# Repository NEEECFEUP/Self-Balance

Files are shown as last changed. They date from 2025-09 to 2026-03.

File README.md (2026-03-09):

# Self Balance

O projeto implementa um controlador PID com base na distância a uma bola e ajusta a posição do servo para manter a distância próxima do **setpoint** definido.

Um **joystick** permite alterar o setpoint e ajustar parâmetros do controlador (Ki e Kd) em tempo real. Um **LCD 16x2 RGB** mostra informação do sistema.

---

## Funcionalidades

- Controlo **PID em tempo real**
- Sensor de distância **VL53L0X**
- Ajuste de **setpoint com joystick**
- Ajuste em tempo real de **Ki e Kd**
- **Filtro passa-baixo** na leitura do sensor
- **Filtro na derivada** para reduzir ruído
- Visualização em **LCD 16x2**
- Debug via **Arduino Serial Plotter**
- Frequência de controlo: **100 Hz**

---

## Hardware

- Arduino
- Sensor **VL53L0X**
- Servo da Hiwonder
- LCD **RGB 16x2 (I2C)**
- Joystick analógico
- Botões de reset

---

## Bibliotecas

Instalar no Arduino IDE:

- `SoftwareSerial`
- `Wire`
- `DFRobot_VL53L0X`
- `ServoHiwonder`
- `rgb_lcd`

---

## Ligações

| Componente | Pino |
|---|---|
| Servo Controller RX | 2 |
| Servo Controller TX | 3 |
| Joystick (setpoint) | A1 |
| Botão joystick | 5 |
| Ajuste Ki | A0 |
| Reset Ki | 4 |
| Ajuste Kd | A2 |
| Reset Kd | 6 |
| VL53L0X | I2C |
| LCD RGB | I2C |

---

## Parâmetros PID

```cpp
float kp = 0.55;
float ki = 0.32;
float kd = 0.4;

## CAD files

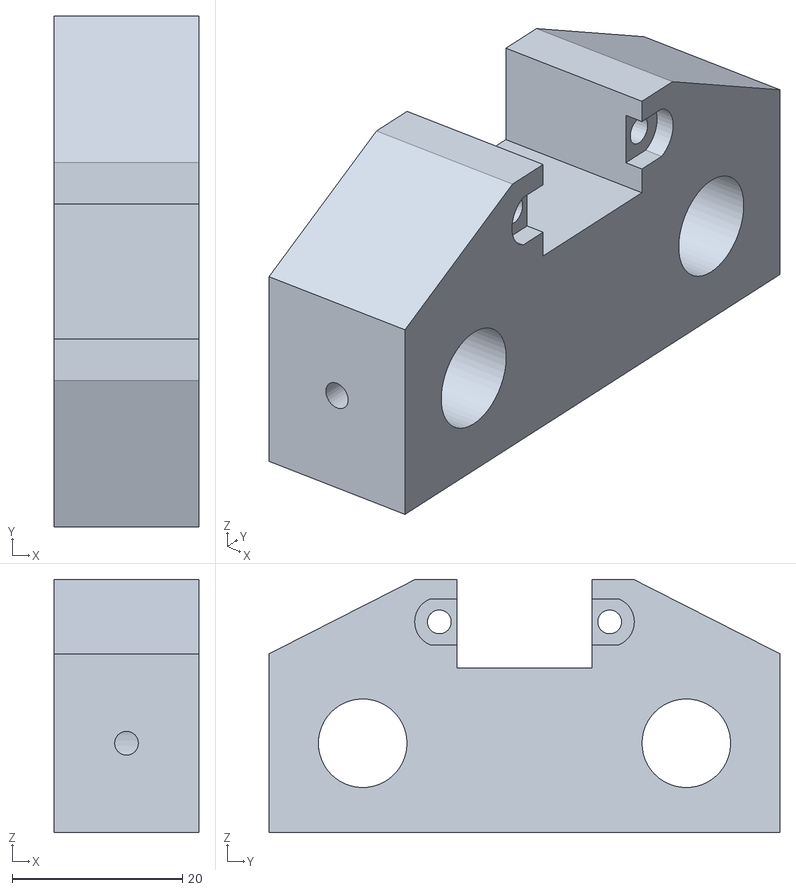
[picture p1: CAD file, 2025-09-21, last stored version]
Self-Balancing c Esteroides/End Cap w ToF.stl
17.0 x 60.0 x 29.7

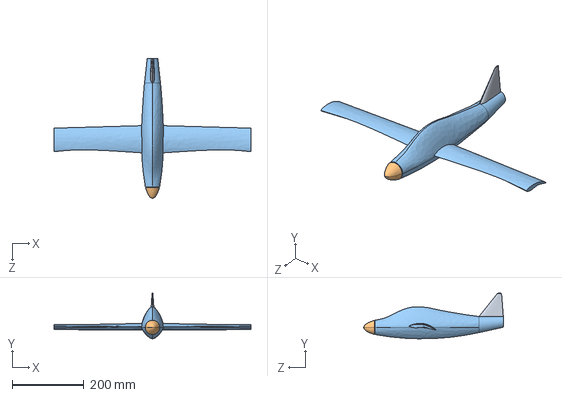
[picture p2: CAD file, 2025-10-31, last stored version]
Self_Balancing 3.0/rc-model-plane-3.snapshot.8/deneme tam çizim 1.STEP
550.0 x 127.3 x 390.0 mm

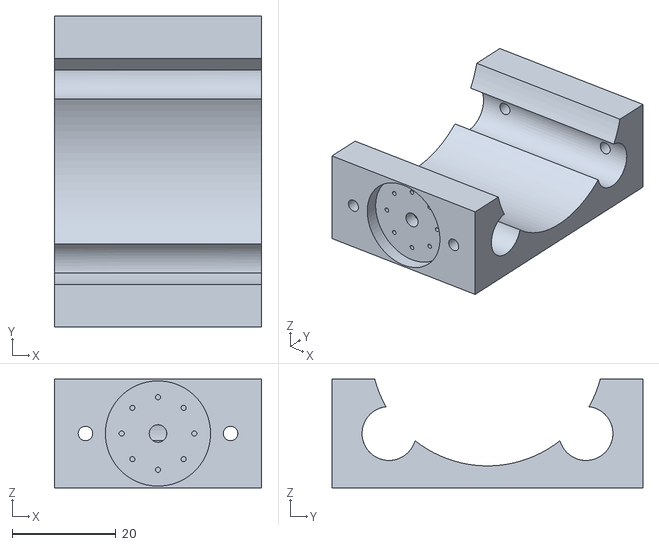
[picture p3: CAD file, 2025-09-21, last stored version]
Self-Balancing c Esteroides/Motor Stand.stl
40.0 x 60.0 x 21.0

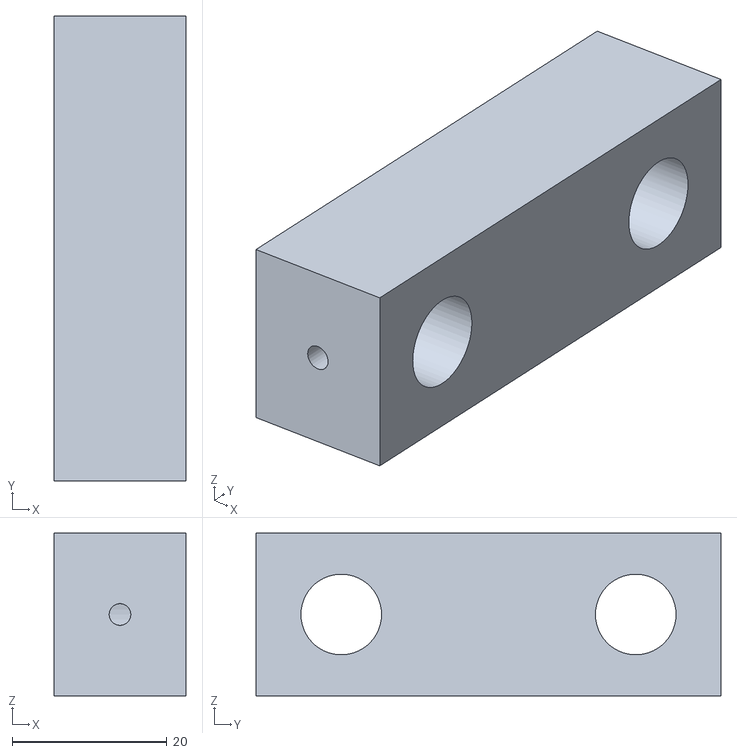
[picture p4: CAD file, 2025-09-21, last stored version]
Self-Balancing c Esteroides/End Cap.stl
17.0 x 60.0 x 21.0

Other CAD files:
Self-Balancing c Esteroides/End Cap w ToF.obj
Self-Balancing c Esteroides/End Cap.obj
Self-Balancing c Esteroides/Motor Stand.obj
Self-Balancing c Esteroides/Self-Balancing c Esteroides v1.f3d
Self_Balancing 3.0/Self-Balancing c Esteroides v10.f3d
Self_Balancing 3.0/Torre_Self_Balancing v1.f3d

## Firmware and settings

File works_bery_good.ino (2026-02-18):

#include <Arduino.h>
#include <SoftwareSerial.h>
#include <Wire.h>
#include "DFRobot_VL53L0X.h"
#include <ServoHiwonder.hpp>
#include "rgb_lcd.h"

// Declarations
SoftwareSerial serial_motors(2, 3);  // RX, TX
ServoController servoCont(serial_motors);
DFRobot_VL53L0X sensor;
rgb_lcd lcd;

// PID vars
float setpoint = 240;   // target distance (mm)

float kp = 0.55;
float ki = 0.32;
float kd = 0.4;

const int servo_center = 600;

float error = 0;
float last_error = 0;
float last_dist = setpoint;
float integral = 0;

// Update Rate
int CRF = 100;   // control rate frequecy (Hz)
const unsigned long interval_ms = 1000 / CRF;
unsigned long lastMillis = 0;
unsigned long lastLcdUpdate = 0;
const unsigned long lcdInterval = 200;   // 5 Hz

const int min_change = 2; // Muda o salto minimo em angulo para fazer, tentei diminuir o jitter mas n fez muito, baixei para 2
static int last_pos = servo_center;

const int pinAnal = A1;  // Pino analógico para o joystick
const int pinButt = 5;  // Pino butao joystick
const int pinKi = A0;  // Pino ki
const int pinRSTKi = 4;  // reset ki
const int pinKd = A2;  // mesmo para a derivada
const int pinRSTKd = 6;  

void setup() {
  Serial.begin(115200);
  serial_motors.begin(115200);

  Wire.begin();
  sensor.begin(0x50);
  sensor.setMode(sensor.eContinuous, sensor.eHigh);
  sensor.start();

  lcd.begin(16, 2);
  lcd.setCursor(0,0);
  lcd.print("Ola...");
  delay(200);

  pinMode(pinButt, INPUT_PULLUP);
  pinMode(pinRSTKi, INPUT_PULLUP);
  pinMode(pinRSTKd, INPUT_PULLUP);

  lastMillis = millis();
}

void loop() {
  unsigned long now = millis();
  if (now - lastMillis >= interval_ms) {

    unsigned long elapsed = now - lastMillis;
    float dt = elapsed / 1000.0;
    lastMillis = now;

    //joy no stick
    int joyValue = analogRead(pinAnal);
    if (joyValue > 550) {
      setpoint += 0.1;  
    }
    else if (joyValue < 470) {
      setpoint -= 0.1;  
    }
    setpoint = constrain(setpoint, 80, 300);
    if (digitalRead(pinButt) == LOW) {
      setpoint = 240;
    }

    // controlar Ki
    joyValue = analogRead(pinKi);
    if (joyValue > 550) {
      ki += 0.001;  
    }
    else if (joyValue < 470) {
      ki -= 0.001;  
    }
    if (digitalRead(pinRSTKi) == LOW) {
      ki = 0.32;
    }

    // controlar kd
    joyValue = analogRead(pinKd);
    if (joyValue > 550) {
      kd += 0.001;  
    }
    else if (joyValue < 470) {
      kd -= 0.001;  
    }
    if (digitalRead(pinRSTKd) == LOW) {
      kd = 0.4;
    }

    float dist = sensor.getDistance();
    // fazer um filtro passa baixo do sinal para tirar jitter
    float alpha = 0.25;   // entre 0 e 1 , menor = mais filtradinho
    static float filtered_dist = 0;
    filtered_dist = alpha * dist + (1 - alpha) * filtered_dist;

    // PID
    error = setpoint - filtered_dist;

    //integral
    integral += error * dt;
    integral = constrain(integral, -400, 400);

    // derivada com filtro alfa male
    static float derivative = 0;
    const float alpha_d = 0.25;
    float d_raw = -(filtered_dist - last_dist) / dt;
    derivative = alpha_d * d_raw + (1 - alpha_d) * derivative;

    float pid = kp * error + ki * integral + kd * derivative;

    last_error = error;
    last_dist = filtered_dist;

    int pos_motor = (int)(servo_center - pid);
    pos_motor = constrain(pos_motor, servo_center - 300, servo_center + 300);
    if (abs(pos_motor - last_pos) >= min_change) {
      servoCont.moveWithTime(1, pos_motor, interval_ms);
      last_pos = pos_motor;
    }

    // Serial debug para o serial plotter do arduino
    Serial.print(0);
    Serial.print(",");
    Serial.print(350);
    Serial.print(",");
    Serial.print(error);
    Serial.print(",");
    Serial.print(setpoint);
    Serial.print(",");
    Serial.print(dist);
    Serial.print(",");
    Serial.println(filtered_dist);

    // LCD
    if (now - lastLcdUpdate >= lcdInterval) {
      lastLcdUpdate = now;

      lcd.setCursor(0, 0);
      lcd.print("D:");
      lcd.print((int)filtered_dist);
      lcd.print(" S:");
      lcd.print((int)setpoint);
      lcd.print("   ");              

      lcd.setCursor(0, 1);
      lcd.print("Ki:");
      lcd.print(ki, 2);
      lcd.print(" Kd:");
      lcd.print(kd, 2);
      lcd.print(" ");                  
    }
  }

}

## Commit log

2025-09-21 Update 3d models
    [End Cap w ToF.stl, End Cap.stl, Motor Stand.stl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]
2025-10-31 3D files for 3.0
    [Self-Balancing c Esteroides v10.f3d, Torre_Self_Balancing v1.f3d, deneme tam çizim 1.STEP]
2026-02-18 Add PID control for servo motor using distance sensor
    This file implements a PID control system using a distance sensor and a servo motor. It includes setup and loop functions to manage sensor readings and motor movements based on the PID algorithm.
2026-02-18 ~0.1% trollagem
    Adjusted PID parameters and control rates for improved performance.
2026-02-18 Adjust setpoint constraints and filtering parameters
2026-03-09 Update README with project details and specifications
    Expanded project documentation with features, hardware, libraries, connections, and PID parameters.
